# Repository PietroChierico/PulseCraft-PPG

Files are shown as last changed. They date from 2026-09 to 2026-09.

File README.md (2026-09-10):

# PulseCraft PPG

An open set of photoplethysmography (PPG) projects that go from a raw optical sensor to a live,
AI-assisted physiological demo. Five small projects, released so anyone can pick them up and
adapt them.






Each project comes with Arduino and ESP32 acquisition firmware, a 3D-printable case for the
MAX3010x sensor, Python code for recording data and extracting features, a small machine-learning
model, and a live GUI demo. A built-in signal simulator lets you run any of the wireless projects
with no hardware at all.

It was built end to end for the Khalifa University CMHS Summer Internship Program 2026, in the
Biomedical Engineering and Biotechnology track, and is free to reuse and adapt.

## The five projects

| # | Project | Question | Signal | Hardware |
|---|---|---|---|---|
| [01](projects/01-physical-activity-recognition/) | Physical activity recognition | Can we tell resting from walking by the motion artifact in PPG? | IR | Wireless (ESP32) |
| [02](projects/02-caffeine-response/) | Caffeine response | When do caffeine-related changes show up in PPG features? | IR | Wired or wireless |
| [03](projects/03-relaxation-score-game/) | Relaxation score game | How much does a 60 s breathing exercise change pulse and HRV features? | IR | Wired or wireless |
| [04](projects/04-biofeedback-spo2-apnea/) | Voluntary-apnea biofeedback | How do the Red and IR amplitudes move during a short, safe breath-hold? | Red + IR | Wired or wireless |
| [05](projects/05-mental-stress-detection/) | Mental stress detection | Can a model separate relaxed from stressed live? | IR | Wired or wireless |

Every project works the same way. You record a fixed protocol with a guided GUI, then you look at
the features and train a small model, then you run that model live on a fresh stream. Learn it
once and the other four have the same shape.

It was first run over about a week, with small groups sharing four sensor nodes.

## What you work through

- How optical PPG works, and why contact, pressure, skin tone and movement change the waveform.
- Basic filtering (detrending and band-pass) and what each step removes, with `visualize_filters.py`.
- Turning a windowed signal into features you can actually interpret.
- Training a small classifier and reading a confusion matrix instead of trusting one accuracy number.
- Running that model on a live signal and seeing where it breaks.
- Handling physiological data responsibly, and the limits of a non-medical device.

## Quick start without hardware

```bash
git clone https://github.com/PietroChierico/PulseCraft-PPG.git
cd PulseCraft-PPG
python -m venv .venv && source .venv/bin/activate   # Windows: .venv\Scripts\activate
pip install -r requirements.txt
```

Start the simulator in one terminal. It behaves exactly like the ESP32 firmware, streaming
`millis,red,ir` over TCP on `127.0.0.1:3333`.

```bash
python tools/ppg_simulator.py --scenario activity
```

Run a project against it in a second terminal. When it asks for a host and port, use `127.0.0.1`
and `3333`.

```bash
cd projects/01-physical-activity-recognition/wireless
python script1_dataset_collection_protocol.py
```

For real hardware, follow [docs/getting-started.md](docs/getting-started.md).

## Hardware

| Part | Example | Notes |
|---|---|---|
| PPG sensor | MAX30102 or MAX30105 breakout | I²C, Red and IR (plus green on the 30105) |
| Wired MCU | Arduino UNO or Nano | USB serial at 115200 baud |
| Wireless MCU | Adafruit Feather ESP32-C6 | WiFi TCP stream, runs on a battery |
| Case | `hardware/stl/` two-piece clip | Keeps the optical contact steady on a wrist or finger |

The full parts list, wiring tables, diagrams and firmware notes are in
[docs/hardware.md](docs/hardware.md).

## What is in the repo

```text
PulseCraft-PPG/
├── projects/     The five projects, each with collect, analyze/train and run-live steps
├── hardware/     Arduino and ESP32 firmware, and the 3D-printable case
├── tools/        ppg_simulator.py for the no-hardware mode, and check_setup.py
├── docs/         Getting started, hardware, signal processing, troubleshooting, FAQ
├── requirements.txt
├── CITATION.cff
├── LICENSE       MIT for code. MEDIA-LICENSE.md is CC BY 4.0 for the STL, photos and diagrams
└── SAFETY.md
```

## Citing

If you use PulseCraft PPG in a course, a workshop, a paper or another kit, please cite it with
[CITATION.cff](CITATION.cff). GitHub shows a "Cite this repository" button.

## License

Code is MIT ([LICENSE](LICENSE)). The STL files, photos and diagrams are CC BY 4.0
([MEDIA-LICENSE.md](MEDIA-LICENSE.md)). Keep attribution to Pietro Chierico when you reuse the
code or the media.

## Safety

For education and research prototyping. It is not a medical device, not a diagnostic tool, and
not for clinical decisions. Project 04 is a short, voluntary, supervised breath-hold and should be
stopped at any discomfort. See [SAFETY.md](SAFETY.md).

## Author

Pietro Chierico, PhD candidate in Biomedical Engineering. Built end to end during a visiting PhD
period at Khalifa University.

Visiting supervisor at Khalifa University, Prof. Mohamed Elgendi. Home PhD supervisor at
Universitat Politècnica de València, Prof. José Javier Rieta. Built for the CMHS Summer Internship
Program 2026, in the Biomedical Engineering and Biotechnology track.

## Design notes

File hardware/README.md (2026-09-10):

# Hardware

Acquisition firmware and the 3D-printable sensor case. The full guide, with the bill of
materials, wiring diagrams, network modes and sample-rate notes, is in
[../docs/hardware.md](../docs/hardware.md).

```text
hardware/
├── wired-arduino/     Arduino UNO and MAX3010x, USB serial at 115200
│   └── project-0X-*/  one streamer sketch per project
├── wireless-esp32/    Adafruit Feather ESP32-C6 and MAX3010x, WiFi TCP port 3333
│   └── project-0X-*/  one streamer sketch per project
└── stl/               two-piece MAX3010x clip enclosure, CC BY 4.0
```

## Which sketch

| Project | Wired | Wireless | Stream |
|---|---|---|---|
| 01, 02, 03, 05 | `wired-arduino/project-0X-ir-streamer/` | `wireless-esp32/project-0X-wifi-ir-streamer/` | IR, `time_us,ir` or `millis,red,ir` |
| 04 | `wired-arduino/project-04-red-ir-streamer/` | `wireless-esp32/project-04-wifi-red-ir-streamer/` | Red and IR |

The MCU only streams samples. All protocol and analysis logic is in the Python projects.

## Arduino library

SparkFun MAX3010x Pulse and Proximity Sensor Library (`MAX30105.h`), from the Arduino Library
Manager. ESP32 sketches also need the esp32 boards package.

## No hardware

`../tools/ppg_simulator.py` replaces the wireless firmware with a synthetic stream on
`127.0.0.1:3333`. Every wireless project runs against it.

## Sensor placement

Keep the contact gentle and steady. Hard pressure collapses perfusion and flattens the waveform.
A fingertip pad gives the strongest signal, a wrist is more realistic but noisier. Use the
printed case and a strap for motion-sensitive work.

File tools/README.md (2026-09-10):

# Tools

Small helpers that make the kit usable before you have hardware, and without it.

## `ppg_simulator.py`

Starts a TCP server that imitates the ESP32 wireless firmware. It accepts one client and then
streams `millis,red,ir` lines at a fixed rate.

```bash
python tools/ppg_simulator.py --scenario activity        # default port 3333
```

| `--scenario` | What it does |
|---|---|
| `plain` | clean resting PPG |
| `activity` | resting pulse with periodic walking bursts, for Project 01 |
| `caffeine` | heart rate drifts up over about 4 minutes, for Project 02 |
| `relaxation` | heart rate down, variability up after about 60 seconds, for Project 03 |
| `apnea` | baseline, then a Red and IR ratio shift during a roughly 30 second hold, then recovery, for Project 04 |
| `stress` | elevated heart rate, low variability, slight tremor, for Project 05 |

Other flags are `--host 0.0.0.0` to expose it on the LAN, `--port`, and `--rate` which defaults
to 100.

Point the project's script or GUI at host `127.0.0.1` and port `3333`. The whole loop, collect
then train then run live, works on simulated data, which is handy for getting familiar with a
project or for testing changes in CI.

## `check_setup.py`

```bash
python tools/check_setup.py                           # are all Python packages importable
python tools/check_setup.py --stream 127.0.0.1:3333   # measure the live sample rate
```

The `--stream` probe reads about 3 seconds and prints the measured rate and value range. If it
shows well under 100 Hz you have a rate mismatch to fix before recording. See
[../docs/hardware.md](../docs/hardware.md#sample-rate).

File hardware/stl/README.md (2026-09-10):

# 3D-printable MAX3010x enclosure

Two files.

- `max30102_base.stl`
- `max30102_shell.stl`

The enclosure steadies the optical contact during wrist or arm PPG recording. Print orientation,
strap fit and sensor tolerances may need small adjustments depending on your printer and your
specific MAX3010x breakout.

These models are licensed CC BY 4.0. Keep attribution to Pietro Chierico.

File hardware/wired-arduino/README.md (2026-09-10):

# Wired Arduino setup

These sketches stream PPG samples from a MAX30102 or MAX30105 to Python over USB serial at
115200 baud.

## Wiring

| MAX3010x | Arduino UNO |
|---|---|
| GND | GND |
| VIN | 3.3V |
| SDA | SDA |
| SCL | SCL |
| INT | not connected |

## Sketches

- `project-01-ir-streamer/arduino_ir_streamer.ino`
- `project-02-ir-streamer/arduino_ir_streamer.ino`
- `project-03-ir-streamer/arduino_ir_streamer.ino`
- `project-04-red-ir-streamer/arduino_red_ir_streamer.ino`
- `project-05-ir-streamer/arduino_ir_streamer.ino`

Close the Arduino IDE Serial Monitor before you connect from Python.

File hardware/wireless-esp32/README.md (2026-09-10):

# Wireless ESP32 setup

These sketches turn the ESP32 into a WiFi TCP PPG streamer.

## Wiring for the Adafruit Feather ESP32-C6

| MAX3010x | ESP32-C6 Feather |
|---|---|
| GND | GND |
| VIN | 3.3V |
| SDA | SDA / IO19 |
| SCL | SCL / IO18 |
| INT | not connected |

## Connection modes

By default the sketch first tries the router WiFi credentials. If those are left as
placeholders it starts an Access Point instead. Connect your computer to that Access Point and
use host `192.168.4.1` and port `3333`.

## Sketches

- `project-01-wifi-ir-streamer/esp32_wireless.ino`
- `project-02-wifi-ir-streamer/esp32_wireless.ino`
- `project-03-wifi-ir-streamer/esp32_wireless.ino`
- `project-04-wifi-red-ir-streamer/esp32_wireless_red_ir.ino`
- `project-05-wifi-ir-streamer/esp32_wireless.ino`

The sketches stream positive raw sensor counts. Project 04 is the only one that needs a paired
Red and IR stream for its Python workflow. The other wireless sketches also send Red and IR, but
the project code uses IR only.

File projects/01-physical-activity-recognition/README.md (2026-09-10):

# Project 01. Physical activity recognition

Can we tell resting from walking using only the motion artifact in a wrist or arm IR PPG signal?

| Item | Value |
|---|---|
| Signal | IR PPG |
| Hardware | Wireless ESP32 is the first choice. A wired Arduino sketch is included as a reference. |
| Feature window | 10 seconds |
| Roughly how long | about 45 minutes once the hardware or simulator is set up |
| No-hardware mode | `python tools/ppg_simulator.py --scenario activity` |

## How it goes

1. Collect with `script1_dataset_collection_protocol.py`. Follow the guided protocol, which is
   20 seconds to stabilise, 60 seconds resting, a 10 second pause, then 60 seconds walking. Each
   10 second window is saved as a labeled feature row. Repeat for several people.
2. Analyze and train with `script2_analysis_training_export.py`. Compare the feature
   distributions for resting against walking, pick a few features, train and test a small
   classifier, and export it.
3. Run live with `script3_live_classification.py`. Stream live, watch the model label resting or
   walking in real time, and try to fool it.

`wireless/Main_page.py` opens a one-page launcher with buttons for the three scripts.

## What you get out of it

Motion artifact is not just noise, it carries information. You see which features respond to
movement, such as derivative spread, high-frequency energy and the noise ratio, and which do not.
And you see why a model that scores perfectly in one room can still be learning the wrong thing.

## Run

```bash
pip install -r ../../../requirements.txt

# no hardware, in two terminals
python ../../../tools/ppg_simulator.py --scenario activity
cd wireless && python script1_dataset_collection_protocol.py    # host 127.0.0.1, port 3333

# real hardware
# flash hardware/wireless-esp32/project-01-wifi-ir-streamer, then use the ESP32 IP
```

## What to expect

With three or more clean sessions from two or more people, a simple classifier gets clearly above
chance. Walking windows show higher derivative standard deviation, higher noise-band energy and a
higher noise ratio. Accuracy across people is lower than within one person, which is a good thing
to discuss.

## Ideas to take it further

Add a third class such as stairs or arm swing. Swap the model for a small random forest and
compare. Split train and test strictly by person and report how much accuracy drops.

## Safety

An educational biomedical-signal demo. Not a medical device, and not for diagnosis or
safety-critical use.

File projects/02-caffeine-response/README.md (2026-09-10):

# Project 02. Caffeine response

How long after a coffee do caffeine-related changes show up in PPG features, and how much does
that differ from one person to another?

| Item | Value |
|---|---|
| Signal | IR PPG |
| Hardware | Wired Arduino or wireless ESP32 |
| Feature window | 10 seconds |
| Roughly how long | one session of about 40 minutes, then about 30 minutes of analysis. The recording spans roughly half an hour of real time. |
| No-hardware mode | `python tools/ppg_simulator.py --scenario caffeine` |

## How it goes

1. Collect with `script1_caffeine_dataset_collection_protocol.py`. Record a baseline, then
   sessions at +5, +10, +15, +20 and +25 minutes after the coffee. Each session is 15 seconds to
   stabilise and 60 seconds of recording, saved as 10 second feature windows tagged with the
   subject and the time point.
2. Analyze with `script2_caffeine_analysis_export.py`. Plot each feature as a change from that
   subject's baseline over time, and export summary CSVs and figures.
3. Interpret with `script3_caffeine_interpretation_assistant.py`. A GUI that helps you see when
   the response appears, which feature moves most, and how consistent it is across people.

## What you get out of it

You work against a personal baseline rather than absolute values. You have to think about
confounds like time of day, posture, temperature and whether the person has eaten, and how to
keep them under control. And you see that a well-known physiological effect can still be small,
noisy and very person-dependent.

## Run

```bash
pip install -r ../../../requirements.txt

python ../../../tools/ppg_simulator.py --scenario caffeine     # no hardware
cd wired && python app.py                                      # or  cd wireless && python app.py
```

## What to expect

Group-level trends, for example a modest shift in heart rate or pulse amplitude, usually appear
by +10 to +20 minutes. Individual curves vary a lot, and some people show almost nothing. That
variability is the point.

## Ideas to take it further

Run a blind decaf against caffeinated control. Fit the time to onset per person and compare it
with the caffeine pharmacokinetics literature.

## Safety

An educational demo. Not a medical device. Respect each participant's caffeine tolerance and
choices, and offer a decaf or no-coffee alternative.

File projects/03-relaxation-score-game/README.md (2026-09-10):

# Project 03. Relaxation score game

How much does one 60 second guided breathing exercise change pulse and heart-rate variability
features, and can we turn that into a live relaxation score?

| Item | Value |
|---|---|
| Signal | IR PPG |
| Hardware | Wired Arduino or wireless ESP32 |
| Feature window | 10 seconds |
| Roughly how long | about 30 minutes per participant |
| No-hardware mode | `python tools/ppg_simulator.py --scenario relaxation` |

## How it goes

1. Collect with `script1_relaxation_dataset_collection.py`. The phases are 20 seconds to
   stabilise, 60 seconds pre-relaxation which is saved, 60 seconds of guided deep breathing, and
   60 seconds post-relaxation which is saved.
2. Analyze and train with `script2_relaxation_analysis_training_export.py`. Quantify the shift
   from pre to post, and fit a model or a scoring function.
3. Play with `script3_relaxation_live_score_game.py`. A live score that rewards a calmer, slower,
   more variable pulse. Participants try breathing techniques to raise it.

## What you get out of it

Slow breathing, around 6 breaths per minute, increases HRV and respiratory sinus arrhythmia, and
you can see it in the waveform. You also see the difference between measuring a change of state
and classifying a person, and you have to design a score that motivates without being gamed by
simply holding still.

## Run

```bash
pip install -r ../../../requirements.txt

python ../../../tools/ppg_simulator.py --scenario relaxation
cd wired && python app_demo3_relaxation.py                     # or  cd wireless && python app_demo3_relaxation.py
```

## What to expect

Most participants show a lower pulse rate and higher beat-to-beat variability after the exercise.
The effect is usually clearer than the caffeine one, and it returns toward baseline within a few
minutes.

## Ideas to take it further

Compare box breathing, 4-7-8 breathing and paced 6 per minute breathing. Add a biofeedback bar
that animates with the breathing cycle.

## Safety

An educational demo. Not a medical device. If a participant feels light-headed during deep
breathing, stop and go back to normal breathing.

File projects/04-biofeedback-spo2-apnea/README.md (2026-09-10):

# Project 04. Voluntary-apnea biofeedback and SpO2 proxy

How do the Red and IR PPG amplitudes, and their ratio, move during a short, safe, voluntary
breath-hold, and what does that tell us about how a pulse oximeter works?

> Safety first. This is a short, voluntary, supervised activity. The participant controls the
> breath-hold and stops at the first sign of discomfort. Never push a breath-hold. The SpO2
> number is an uncalibrated educational proxy, not a measurement.

| Item | Value |
|---|---|
| Signal | Red and IR PPG, both channels are required |
| Hardware | Wired Arduino or wireless ESP32, dual-channel sketch |
| Window | 5 second rolling Red and IR ratio windows inside a full-trial CSV |
| Roughly how long | about 20 minutes per participant |
| No-hardware mode | `python tools/ppg_simulator.py --scenario apnea` |

## How it goes

1. Collect with `script1_spo2_apnea_collection.py`. The phases are 30 seconds of baseline, a
   voluntary apnea that the participant starts, then 60 seconds of recovery. Red and IR are
   recorded together.
2. Analyze with `script2_spo2_apnea_analysis.py`. Compute AC over DC for each channel and the
   ratio of ratios, then plot how it drifts during the hold and recovers afterward.
3. Challenge with `script3_spo2_apnea_interactive_challenge.py`. A live biofeedback view of the
   ratio and a proxy trend during a supervised hold.

## What you get out of it

You see why oximetry needs two wavelengths and uses `(AC/DC)_red / (AC/DC)_ir`, what a real
device calibrates with empirical curves and why this proxy is not that, and the physiological
lag, since the ratio keeps drifting for several seconds after breathing resumes.

## Run

```bash
pip install -r ../../../requirements.txt

python ../../../tools/ppg_simulator.py --scenario apnea
cd wired && python app_demo4_spo2_apnea.py                     # or  cd wireless && python app_demo4_spo2_apnea.py
```

Flash the red and ir sketch under `hardware/*/project-04-*red-ir*`.

## What to expect

During a 20 to 30 second hold the ratio of ratios shifts slightly and the proxy trends downward,
then overshoots and recovers over 30 to 60 seconds. The magnitudes vary and are not clinically
meaningful.

## Ideas to take it further

Compare finger against wrist placement. Add a simple two-point linear calibration against a real
fingertip oximeter, clearly labeled as a classroom exercise.

## Safety

See the box above and [../../SAFETY.md](../../SAFETY.md). Stop at once on dizziness, pain,
anxiety or shortness of breath. Not for anyone with a relevant cardiovascular or respiratory
condition.

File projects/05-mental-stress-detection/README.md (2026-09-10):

# Project 05. Mental stress detection

Can a small model separate relaxed from stressed, live, using PPG-derived waveform, pulse and HRV
features?

| Item | Value |
|---|---|
| Signal | IR PPG |
| Hardware | Wired Arduino or wireless ESP32 |
| Feature window | 10 seconds |
| Roughly how long | about 35 minutes to collect, then about 25 minutes of analysis |
| No-hardware mode | `python tools/ppg_simulator.py --scenario stress` |

## How it goes

1. Collect with `script1_stress_dataset_collection.py`. A multi-phase protocol that alternates
   calm baselines with cognitive stressors such as mental arithmetic, a timed reaction task and
   cognitive interference. Each 10 second window is labeled `Relaxed` or `Stressed`.
2. Analyze and train with `script2_stress_analysis_training_export.py`. See which features
   separate the classes, train and test, then export the model.
3. Challenge with `script3_stress_live_detection_challenge.py`. A live `Relaxed` against
   `Stressed` readout. Participants try to stay relaxed under a stressor.

## What you get out of it

Acute stress activates the sympathetic nervous system, which raises heart rate, lowers HRV and
subtly changes the waveform. Stress labels are noisy, since a stress task is not stressful for
everyone every time. You also deal with feature stability, class balance and why per-session
normalization matters.

## Run

```bash
pip install -r ../../../requirements.txt

python ../../../tools/ppg_simulator.py --scenario stress
cd wired && python app_demo5_stress.py                         # or  cd wireless && python app_demo5_stress.py
```

The wired serial format is shown in `wired/arduino_serial_ppg_format_example.ino`.

## What to expect

Accuracy within one person is usually good, and the model leans on HRV-proxy and pulse-rate
features. Generalization across people is weak with a small dataset, which is expected and worth
writing up.

## Ideas to take it further

Add a neutral third class and watch accuracy fall. Test the model on a fresh session recorded a
day later. Add a self-reported stress slider from 1 to 10 and correlate it with the model score.

## Safety

An educational demo. Not a medical device and not a psychological assessment. The stressor tasks
are mild and voluntary, and participants can stop at any time.

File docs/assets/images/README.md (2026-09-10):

# Image slots

Add your public setup photos here after checking them for privacy.

Some names that fit the docs.

- `hardware/wired-arduino-overview.jpg`
- `hardware/wireless-esp32-overview.jpg`
- `hardware/max30102-wiring-closeup.jpg`
- `stl/max30102-case-assembled.jpg`
- `project-04/red-ir-sensor-contact.jpg`

Avoid photos with faces, private notes, ID cards, or visible personal data unless you have
explicit permission.

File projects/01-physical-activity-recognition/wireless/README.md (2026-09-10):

# Project 01. Physical activity recognition, wireless workflow

This is the ESP32 WiFi version. Flash the matching sketch from `hardware/wireless-esp32/`. Use host `192.168.4.1` and port `3333` in the board's Access Point mode, or the IP from the Serial Monitor in router mode. With no hardware, run `tools/ppg_simulator.py` and use host `127.0.0.1`.

## Run

```bash
pip install -r ../../../requirements.txt
python ../../../tools/ppg_simulator.py --scenario activity   # no hardware, in a separate terminal
python Main_page.py   # a launcher page with buttons for the scripts below
# or run the steps in order
python script1_dataset_collection_protocol.py
python script2_analysis_training_export.py
python script3_live_classification.py
```

## Files

- `Main_page.py` is a small launcher page with buttons for the three scripts.
- `script1_dataset_collection_protocol.py` is step 1, collect a labeled dataset with a guided protocol.
- `script2_analysis_training_export.py` is step 2, look at the features, train and test a small model, then export it.
- `script3_live_classification.py` is step 3, stream live and classify or score in real time.
- `demo_1.py` is a helper.
- `ppg_feature_utils.py` is shared feature extraction.

## Notes

Keep the sample rate identical across collect, train and live. See `../../../docs/hardware.md`.

Do not commit recorded CSVs or trained models. `.gitignore` already blocks them.

Firmware for this version is under `hardware/wireless-esp32/project-01-*`.

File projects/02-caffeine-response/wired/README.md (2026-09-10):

# Project 02. Caffeine response, wired workflow

This is the Arduino serial version. Flash the matching sketch from `hardware/wired-arduino/`, then close the Arduino Serial Monitor before you connect from Python. Set the COM or tty port in the GUI (in Arduino IDE, under Tools then Port).

## Run

```bash
pip install -r ../../../requirements.txt
python app.py   # a launcher page with buttons for the scripts below
# or run the steps in order
python script1_caffeine_dataset_collection_protocol.py
python script2_caffeine_analysis_export.py
python script3_caffeine_interpretation_assistant.py
```

## Files

- `app.py` is a small launcher page with buttons for the three scripts.
- `script1_caffeine_dataset_collection_protocol.py` is step 1, collect a labeled dataset with a guided protocol.
- `script2_caffeine_analysis_export.py` is step 2, look at the features, train and test a small model, then export it.
- `script3_caffeine_interpretation_assistant.py` is step 3, stream live and classify or score in real time.
- `visualize_filters.py` is a live viewer for raw against filtered signal.

## Notes

Keep the sample rate identical across collect, train and live. See `../../../docs/hardware.md`.

Do not commit recorded CSVs or trained models. `.gitignore` already blocks them.

Firmware for this version is under `hardware/wired-arduino/project-02-*`.

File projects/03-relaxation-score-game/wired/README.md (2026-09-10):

# Project 03. Relaxation score game, wired workflow

This is the Arduino serial version. Flash the matching sketch from `hardware/wired-arduino/`, then close the Arduino Serial Monitor before you connect from Python. Set the COM or tty port in the GUI (in Arduino IDE, under Tools then Port).

## Run

```bash
pip install -r ../../../requirements.txt
python app_demo3_relaxation.py   # a launcher page with buttons for the scripts below
# or run the steps in order
python script1_relaxation_dataset_collection.py
python script2_relaxation_analysis_training_export.py
python script3_relaxation_live_score_game.py
```

## Files

- `app_demo3_relaxation.py` is a small launcher page with buttons for the three scripts.
- `script1_relaxation_dataset_collection.py` is step 1, collect a labeled dataset with a guided protocol.
- `script2_relaxation_analysis_training_export.py` is step 2, look at the features, train and test a small model, then export it.
- `script3_relaxation_live_score_game.py` is step 3, stream live and classify or score in real time.
- `visualize_filters.py` is a live viewer for raw against filtered signal.

## Notes

Keep the sample rate identical across collect, train and live. See `../../../docs/hardware.md`.

Do not commit recorded CSVs or trained models. `.gitignore` already blocks them.

Firmware for this version is under `hardware/wired-arduino/project-03-*`.

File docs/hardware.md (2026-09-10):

# Hardware

## Bill of materials

Per sensor node. Prices are rough 2026 street prices, for planning only.

| Part | Qty | ~USD | Notes |
|---|----:|-----:|---|
| MAX30102 or MAX30105 breakout | 1 | 5 to 12 | The 30105 adds a green LED. Either works. Prefer a board with a 3.3 V regulator and level shifting. |
| Arduino UNO or Nano (wired) | 1 | 8 to 25 | Any AVR board with I²C. |
| Adafruit Feather ESP32-C6 (wireless) | 1 | 15 to 20 | Other ESP32 boards work. Update the I²C pins in the sketch. |
| LiPo battery 400 to 1000 mAh (wireless) | 1 | 6 to 10 | JST-PH, for recording without a cable. |
| Dupont jumper wires | 4 | 1 | GND, 3V3, SDA, SCL. |
| USB cable | 1 | 2 | Data-capable, not charge-only. |
| 3D-printed case (`hardware/stl/`) | 1 | about 0.2 filament | Two-piece clip that steadies the optical contact. |
| Hook-and-loop strap | 1 | 1 | Holds the case on a wrist or finger. |

Twelve people in groups of three need four nodes. Budget one spare sensor.

## Wiring

The same four wires for every board. The MAX3010x runs at 3.3 V logic.

```text
 MAX3010x            Arduino UNO/Nano        Feather ESP32-C6
 --------            ---------------         ----------------
   GND  ------------------ GND ------------------ GND
   VIN  ------------------ 3.3V ----------------- 3.3V
   SDA  ------------------ A4 / SDA ------------- SDA (IO19)
   SCL  ------------------ A5 / SCL ------------- SCL (IO18)
   INT  ------  not connected  ------
```

```mermaid
flowchart LR
  S["MAX3010x sensor"] -- "I2C" --> M["MCU (Arduino UNO or ESP32-C6)"]
  M -- "USB serial 115200" --> PC1["PC, wired projects"]
  M -- "WiFi TCP port 3333, millis,red,ir" --> PC2["PC, wireless projects"]
  SIM["tools/ppg_simulator.py"] -. "no hardware" .-> PC2
```

## Firmware

The sketches live in `hardware/`. Each one is a self-contained streamer with no project logic on
the MCU.

| Project | Wired sketch | Wired stream | Wireless sketch | Wireless stream |
|---|---|---|---|---|
| 01, 02, 03, 05 | `wired-arduino/project-0X-ir-streamer/` | `time_us,ir` | `wireless-esp32/project-0X-wifi-ir-streamer/` | `millis,red,ir` |
| 04 | `wired-arduino/project-04-red-ir-streamer/` | `time_us,red,ir` | `wireless-esp32/project-04-wifi-red-ir-streamer/` | `red,infrared` |

The Python parsers take the last numeric value or values on each line, so timestamped and bare
formats both work. Projects 01 to 03 and 05 use IR only. Project 04 needs paired Red and IR.

### Required Arduino library

SparkFun MAX3010x Pulse and Proximity Sensor Library (`MAX30105.h`), installed from the Arduino
Library Manager. For ESP32 you also need the esp32 boards package.

### Wireless network modes

In Access Point mode, which is the default, leave `WIFI_SSID` and `WIFI_PASSWORD` on their
placeholders. The board creates `PPG_STREAM_groupN` with password `12345678`. Connect the PC's
WiFi to it and use host `192.168.4.1` and port `3333`. This is best for classrooms with
locked-down WiFi.

In router mode, set your WiFi credentials in the sketch, read the assigned IP from the Serial
Monitor, and use that IP with port `3333`.

## Sample rate

The sensor's effective output rate is `SAMPLE_RATE / SAMPLE_AVERAGE`.

| Sketch | `SAMPLE_RATE` | `SAMPLE_AVERAGE` | Effective rate | Matches the Python default of 100 Hz |
|---|---:|---:|---:|:--:|
| Wired Arduino (shipped) | 100 | 1 | 100 Hz | yes |
| Wireless ESP32 (shipped) | 100 | 1 | 100 Hz | yes |

Older copies of the ESP32 sketch shipped with `SAMPLE_AVERAGE = 4`, an effective 25 Hz, which did
not match the Python default. If `tools/check_setup.py --stream` shows about 25 Hz, set
`SAMPLE_AVERAGE = 1` in the sketch, or set `sampling_rate_hz = 25.0` in the project config.

If you deliberately change the rate or averaging, keep the value identical across collection,
training and live inference, and record the dataset again.

## Sensor placement

Keep the contact gentle and steady. Hard pressure collapses perfusion and flattens the waveform.
A fingertip pad gives the strongest signal. A wrist is more realistic but noisier. Shield the
sensor from strong direct light, and keep the cable still for the motion-sensitive Project 01.
Give the signal about 15 to 20 seconds to settle before recording. Every protocol already builds
that in.

## Photos

Add setup photos to `docs/assets/images/` under `hardware/`, `stl/` and `project-04/`. Avoid
faces, ID badges, screens showing participant data, and handwritten notes.

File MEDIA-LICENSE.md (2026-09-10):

# Media license

Code in this repository is under the MIT License in `LICENSE`.

The non-code assets are under the Creative Commons Attribution 4.0 International License
(CC BY 4.0). This covers the STL and 3D-printable files, setup photos, wiring diagrams, project
images, and any other visual or media assets added under `docs/assets/images/`.

Use this attribution line when you reuse or adapt them.

```text
PulseCraft PPG media assets by Pietro Chierico, licensed under CC BY 4.0.
```

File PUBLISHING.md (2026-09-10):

# Publishing and discoverability

Notes for publishing this repository, or a fork of it, and for making it easy to find.

## Before the first push

Check that nothing private is included.

- No CSVs, models, or `data/` and `results/` folders. `.gitignore` should already prevent this.
- Setup photos under `docs/assets/images/` have no faces, ID badges, screens showing participant
  data, or handwritten notes.
- No names beyond the author and the two named supervisors.

## Create the repo and push

```bash
git init
git add .
git commit -m "PulseCraft PPG 1.0.0"
git branch -M main
git remote add origin https://github.com/your-handle/PulseCraft-PPG.git
git push -u origin main
git tag v1.0.0 && git push --tags
```

## Repo settings that make it findable

Open the repo's About panel (the gear icon on the main page) and set the following.

Description.

```
Open photoplethysmography (PPG) projects. Arduino and ESP32 acquisition, a MAX30102 sensor case, Python feature extraction, small ML models, live demos, and a no-hardware simulator. Five small projects.
```

Website, `https://your-handle.github.io/PulseCraft-PPG/`.

Topics, added one at a time.

```
photoplethysmography  ppg  biomedical-signal-processing  wearable-sensing  digital-health
heart-rate-variability  pulse-oximetry  arduino  esp32  max30102  max30105  machine-learning
biomedical-engineering  stem-education  teaching-materials  open-educational-resources
signal-processing  python
```

In the repo settings, enable Issues and Discussions. Under Pages, set the source to a branch,
pick `main` and the `/docs` folder. Add a social preview image under Social preview, a photo of
the setup or a diagram works well.

For the first GitHub Release, tag `v1.0.0` and paste the 1.0.0 section of `CHANGELOG.md`.

## Optional, a citable DOI

Sign in to Zenodo with GitHub, turn on the switch for this repository in the Zenodo GitHub
settings, then publish a GitHub Release. Zenodo mints a DOI for it. Add the DOI badge to
`README.md` and a `doi:` field to `CITATION.cff`.

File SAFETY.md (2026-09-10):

# Safety and scope

## What this is

An educational and research-prototyping kit. It is not a medical device, not a diagnostic tool,
and not intended for clinical monitoring or clinical decisions.

PPG signals and every score derived from them depend heavily on sensor placement, motion,
contact pressure, ambient light, skin tone, individual physiology and calibration. Treat all
outputs as teaching artifacts.

## General rules

- Use it only for education and research prototyping.
- Do not use any output for medical diagnosis or clinical decisions.
- Keep sensor contact gentle. Too much pressure hurts and degrades the signal.
- Do not collect or publish participant data without the right consent and approvals. See
  [DATA_POLICY.md](DATA_POLICY.md).

## Extra rules for Project 04, voluntary apnea

- It is a short, voluntary, supervised activity only.
- The participant starts and ends the breath-hold, and stops at the first sign of discomfort.
- Never encourage longer holds, competition, or repeated holds.
- Stop at once on dizziness, pain, discomfort, anxiety, tingling, or shortness of breath.
- Not for anyone who is pregnant, or who has a cardiovascular, respiratory or seizure condition,
  or who is uncomfortable with the activity for any reason. Offer them the simulator scenario
  instead.
- The displayed SpO2 value is an uncalibrated educational proxy, not a measurement. Do not use it
  to reassure or alarm anyone.

## If you adapt this for a course

Follow your institution's ethics or IRB process for any human-subject data you keep or analyse
beyond a live in-class demo.

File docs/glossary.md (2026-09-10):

# Glossary

**PPG (photoplethysmography).** Measuring blood-volume changes in tissue from how much light a
skin site absorbs or reflects over time. The pulsatile part tracks the heartbeat.

**IR and Red channels.** The two LEDs on a MAX3010x. IR alone is enough for pulse-shape work.
The Red and IR pair together is used for oxygenation proxies.

**AC and DC components.** DC is the slowly varying baseline from tissue and venous blood. AC is
the pulsatile component from arterial pulsation.

**Motion artifact.** Signal corruption from the sensor moving against the skin. It dominates
Project 01.

**Detrending, or high-pass filter.** Removing the slow baseline so the pulse is centred on zero.

**Band-pass filter.** Keeping only a frequency band, here about 0.5 to 3 Hz, the heart-rate range.

**Feature window.** A fixed-length slice of signal, 5 to 10 seconds, summarised into a row of
numbers.

**Feature.** One number describing a window, for example spectral centroid or derivative
standard deviation.

**HRV (heart-rate variability).** Beat-to-beat timing variation, a proxy for autonomic balance.

**Ratio of ratios.** `(AC_red/DC_red) / (AC_ir/DC_ir)`, the quantity a pulse oximeter calibrates
into SpO2. It is left uncalibrated here.

**SpO2.** Peripheral blood oxygen saturation. Project 04 outputs a proxy, not a measurement.

**Confusion matrix.** A table of predicted against true labels, the honest way to read classifier
performance.

**Leakage.** When information from the test set reaches training, for example the same recording
session on both sides, which inflates accuracy.

**Access Point (AP) mode.** The ESP32 makes its own WiFi network instead of joining a router.

**Sampling rate.** Samples per second. It must be identical across collection, training and live
inference.

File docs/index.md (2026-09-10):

# PulseCraft PPG

An open set of photoplethysmography (PPG) projects that go from a raw optical sensor to a live,
AI-assisted physiological demo.

Arduino and ESP32 acquisition firmware, a 3D-printable MAX3010x case, Python code for recording
data and extracting features, small machine-learning models, live GUI demos, and a signal
simulator so you can run everything before any hardware arrives.

Code is at <https://github.com/PietroChierico/PulseCraft-PPG>.

Start with [Getting started](getting-started.md). See also [Hardware](hardware.md),
[Signal processing](signal-processing.md),
[Signal-quality checklist](signal-quality-checklist.md),
[Troubleshooting](troubleshooting.md), [FAQ](faq.md) and [Glossary](glossary.md).

## Projects

| # | Project | Signal | Hardware |
|---|---|---|---|
| 01 | Physical activity recognition (resting vs walking) | IR | Wireless |
| 02 | Caffeine response over time | IR | Wired or wireless |
| 03 | Relaxation score game (breathing) | IR | Wired or wireless |
| 04 | Voluntary-apnea biofeedback with a SpO2 proxy | Red + IR | Wired or wireless |
| 05 | Mental stress detection (live classifier) | IR | Wired or wireless |

See [Project protocols](project-protocols.md) for the recording steps.

## Attribution

Designed and built by **Pietro Chierico** during a visiting PhD period at **Khalifa University**.
Visiting supervisor at Khalifa University, **Prof. Mohamed Elgendi**. Home PhD supervisor at
Universitat Politècnica de València, **Prof. José Javier Rieta**. Built for the **CMHS Summer
Internship Program 2026**, in the Biomedical Engineering and Biotechnology track.

For education and research only. Not a medical device.

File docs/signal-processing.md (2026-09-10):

# Signal processing, in brief

This is the conceptual map. The exact details are in each project's `ppg_*_features.py` or
`ppg_feature_utils.py`.

## Pipeline

Raw counts become a window of 5 to 10 seconds. The window is detrended and band-passed, then
turned into features. A small model maps the features to a label or a score.

## 1. Windowing

The stream is cut into fixed windows, 10 seconds for projects 01 to 03 and 05, and a 5 second
rolling window for the SpO2 proxy in 04. One window makes one feature row. The window is the
unit of both training and live prediction.

## 2. Filtering

A high-pass around 0.5 Hz removes the slow baseline wander from breathing and perfusion drift, so
the pulse sits on zero. A band-pass of roughly 0.5 to 3 or 4 Hz keeps the heart-rate band and
attenuates DC and high-frequency noise. Run `visualize_filters.py` in any project to see raw
against filtered, live, and get a feel for what each filter throws away.

The filtering is kept simple and causal-friendly so the same ideas carry over to an embedded or
wearable context.

## 3. Features

| Group | Examples | Reads as |
|---|---|---|
| Amplitude and spread | mean, std, 5 to 95 percent range, IQR, detrended std | perfusion strength, gross motion |
| Shape and derivative | mean absolute derivative, derivative std, zero-crossing rate | steepness and regularity of the pulse |
| Spectral | pulse-band energy, noise-band energy, noise ratio, spectral centroid | how clean the signal is and where its energy sits |
| Rate and variability (03, 05) | pulse rate, inter-beat interval, HRV proxies | autonomic state |
| Red and IR ratio (04 only) | ratio of ratios, AC over DC per channel | oxygenation proxy, not calibrated SpO2 |

The features are chosen to be interpretable. You should be able to say why a feature moved, not
just that the model score changed.

## 4. Model

A small scikit-learn classifier, either logistic regression or a small tree ensemble depending
on the project. It is kept small on purpose. It trains in seconds on a class-sized dataset, the
decision boundary can be inspected feature by feature in `script2_*`, and its size forces the
question of whether a result is real physiology or just the room.

Always read the confusion matrix, and test on a session the model never saw.

## 5. Honest limits

PPG features depend on placement, contact pressure, skin tone, ambient light, motion and
individual physiology. Cross-subject models are weak with small datasets. The SpO2 value in
Project 04 is an educational ratio proxy, not a validated measurement. Treat every output as a
teaching artifact.

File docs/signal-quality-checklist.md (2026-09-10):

# Signal-quality checklist

Run through this before trusting any recording.

- [ ] Sensor powered from 3.3 V, not 5 V.
- [ ] Serial Monitor closed for wired, or the right host and port for wireless.
- [ ] `python tools/check_setup.py --stream <host:port>` shows about 100 Hz, or your configured rate.
- [ ] Sensor resting on the skin with light, steady contact, not pressed.
- [ ] Consistent measurement site (fingertip pad, wrist, and so on), and note which one.
- [ ] Cable and board still and supported. This matters most for Project 01.
- [ ] Not under strong direct light.
- [ ] Full stabilisation phase waited out before recording.
- [ ] Band-pass output in `visualize_filters.py` looks like a clean, regular pulse.
- [ ] No flat-topping or clipping at the top or bottom of the raw trace.

A quick sanity check. Estimate the heart rate by eye from the band-pass trace and confirm it
matches the person. If the waveform is flat, clipped or irregular, fix the setup and record
again.

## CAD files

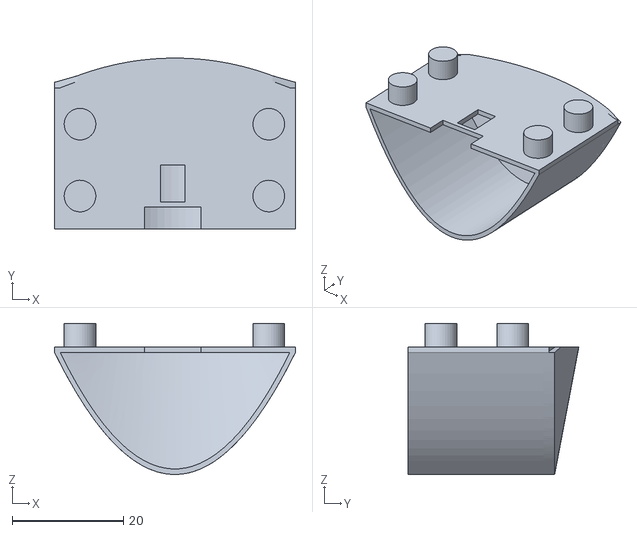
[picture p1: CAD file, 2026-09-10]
hardware/stl/max30102_shell.stl
43.4 x 30.8 x 27.2

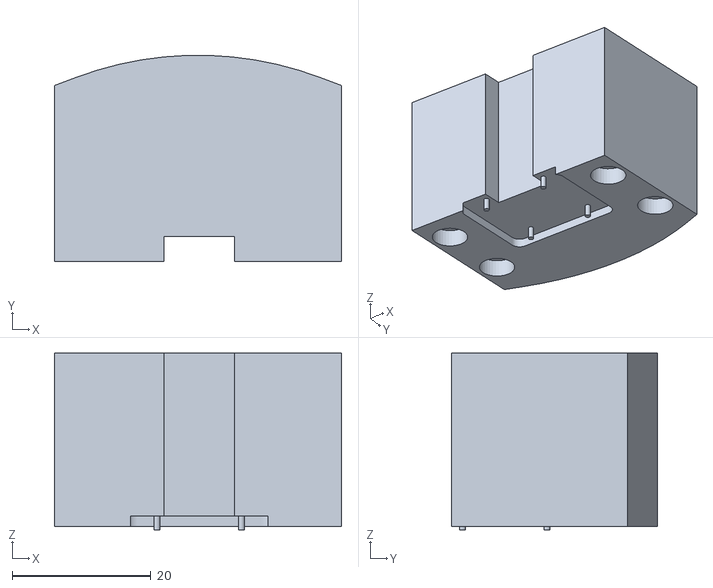
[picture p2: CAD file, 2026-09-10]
hardware/stl/max30102_base.stl
41.4 x 29.7 x 25.5

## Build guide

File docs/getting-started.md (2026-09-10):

# Getting started

There are two paths. Do A first, since it needs no hardware and takes about five minutes. Then
do B when you have a sensor.

## A. Run a project with the simulator

```bash
python -m venv .venv && source .venv/bin/activate     # Windows: .venv\Scripts\activate
pip install -r requirements.txt
python tools/check_setup.py                            # confirms the environment
```

Start the synthetic stream. It behaves like the ESP32 firmware, running a TCP server on port
3333 and sending `millis,red,ir` lines at 100 Hz.

```bash
python tools/ppg_simulator.py --scenario activity      # also caffeine, relaxation, apnea, stress
```

In a second terminal, run any wireless project. When a script asks for a host and a port, use
`127.0.0.1` and `3333`.

```bash
cd projects/01-physical-activity-recognition/wireless
python script1_dataset_collection_protocol.py
```

You can do the whole loop, collect then train then run live, entirely on simulated data. This is
the easiest way to get familiar with a project before the hardware is set up.

## B. Run a project with real hardware

### 1. Build the sensor node

Wire the MAX3010x to the board using the tables in [hardware.md](hardware.md), and print the case
in `hardware/stl/` if you want one.

### 2. Flash the firmware

Install the Arduino IDE and the SparkFun MAX3010x library (Library Manager, search "MAX3010x").

For the wired setup, open `hardware/wired-arduino/project-0X-*/*.ino`, select your board and
port, and upload. Close the Serial Monitor afterwards, because Python needs the port.

For the wireless setup, open `hardware/wireless-esp32/project-0X-*/*.ino`. Leave the WiFi fields
on their placeholders and the board makes its own network `PPG_STREAM_groupN` (password
`12345678`), or enter your router credentials instead. Upload, then open the Serial Monitor once
to read the IP.

### 3. Connect

For the wired setup, find the COM or tty port in Arduino IDE under Tools then Port. The Python
GUI has a port field.

For the wireless setup on the board's own network, connect your computer's WiFi to
`PPG_STREAM_groupN`, then use host `192.168.4.1` and port `3333`. In router mode, use the IP
printed in the Serial Monitor and port `3333`.

Check the stream first with `python tools/check_setup.py --stream 192.168.4.1:3333`. It reports
the measured sample rate and a short waveform preview.

### 4. Run the project

Open the project folder and follow its `README.md`. Each project has an `app.py` launcher, a
small local web page with buttons, and three numbered scripts you can also run directly.

```text
script1_*   collect a labeled dataset with a guided protocol
script2_*   analyze features, train and test a model, export it
script3_*   stream live and classify or score in real time
```

Before a real recording, run through the [signal-quality checklist](signal-quality-checklist.md).

## Sample rate must match everywhere

Collection, training and live inference all assume the same sample rate. The Python config
default is 100 Hz. If you change the firmware sample rate or averaging, update `sampling_rate_hz`
in the project config and record again. See [hardware.md](hardware.md#sample-rate).

## If something breaks

See [troubleshooting.md](troubleshooting.md). The usual causes are a Serial Monitor left open,
the wrong host or port, the sensor not touching skin properly, and a sample-rate mismatch.

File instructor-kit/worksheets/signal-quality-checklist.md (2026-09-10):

# Signal-quality checklist

Group: _______________  Node ID: ______  Date/time: ______________

Run through this before you trust any recording.

- [ ] Sensor powered from **3.3 V** (not 5 V).
- [ ] Serial Monitor closed (wired) / correct host + port (wireless).
- [ ] `python tools/check_setup.py --stream <host:port>` shows **~100 Hz** (or your configured rate).
- [ ] Sensor rests on the skin with **light, steady** contact — not pressed.
- [ ] Site chosen and recorded: ☐ fingertip pad ☐ wrist ☐ other: ______
- [ ] Cable/board is still and supported (critical for Project 01).
- [ ] Not under strong direct light.
- [ ] Waited the full stabilisation phase before recording.
- [ ] Band-pass output in `visualize_filters.py` looks like a clean, regular pulse.
- [ ] No flat-topping / clipping at the top or bottom of the raw trace.

**Attach:** one screenshot of raw vs band-pass, annotated with the heart rate you estimate by eye.

Estimated heart rate by eye: ______ bpm  ·  Looks clean? ☐ yes ☐ borderline ☐ re-record

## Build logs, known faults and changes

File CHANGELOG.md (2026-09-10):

# Changelog

The format loosely follows [Keep a Changelog](https://keepachangelog.com/). Versioning is
semantic.

## 1.0.0, 2026-09

First public release.

- Five projects (activity recognition, caffeine response, relaxation, an apnea and SpO2 proxy,
  stress detection). Each one follows the same collect, analyze and train, run live pattern, in
  wired and wireless variants.
- Arduino UNO and Adafruit Feather ESP32-C6 acquisition firmware. The ESP32 sketches stream a
  true 100 Hz (`SAMPLE_AVERAGE = 1`) to match the Python `sampling_rate_hz` default.
- Two-piece 3D-printable MAX3010x enclosure in `hardware/stl/`.
- `tools/ppg_simulator.py`, a synthetic Red and IR TCP stream so every wireless project runs
  with no hardware, with six scenario presets.
- `tools/check_setup.py`, an environment and live-stream sample-rate check.
- `docs/` covering getting started, hardware, signal processing, the signal-quality checklist,
  troubleshooting, an FAQ, a glossary and the project protocols.
- GitHub scaffolding, issue and PR templates, a Code of Conduct, `CITATION.cff`, and a CI syntax
  check.

### Notes

The firmware is checked statically only. It has not been re-tested on hardware for this release.

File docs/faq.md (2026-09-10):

# FAQ

**Do I need hardware to try this?**
No. `tools/ppg_simulator.py` produces synthetic Red and IR PPG on TCP `127.0.0.1:3333`, exactly
like the ESP32 firmware. Every wireless project runs against it end to end.

**Which sensor should I buy?**
A MAX30102 or a MAX30105. Either one works. The 30105 adds a green LED that is unused here. Pick
a breakout with an onboard 3.3 V regulator.

**Arduino or ESP32?**
Wired Arduino is the simplest and most stable option on a lab bench. Wireless ESP32 is better for
the motion projects and for a wearable feel. Projects 02 to 05 support both. Project 01 is
wireless first.

**How much time does it take?**
Each project is a short session once the hardware or the simulator is ready. The first run took
about a week with small groups, but the projects are independent, so do one or all five at
whatever pace suits you.

**Can I keep the recordings?**
Yes, locally. Do not commit them. `.gitignore` blocks CSVs, models and output folders by
default. See `DATA_POLICY.md`.

**Is the SpO2 number in Project 04 real?**
No. It is an uncalibrated ratio-of-ratios proxy for teaching. It is not a pulse oximeter.

**Can I use a different board, a Raspberry Pi, or phone-camera PPG?**
The Python side only needs a line-based stream of numbers. Any source that sends `ir` or
`millis,red,ir` lines over serial or TCP will work. Change the host and port, or the serial port
name, in the GUI.

**Why are the models so small?**
So they train in seconds on a laptop, stay interpretable, and make overfitting on a small
dataset obvious. Swapping in a bigger model is an easy next step.

**What can I change and redistribute?**
Everything. Code is MIT, media is CC BY 4.0. Keep attribution to Pietro Chierico and cite the
repo.

**How do I cite it?**
Use `CITATION.cff`. GitHub shows a "Cite this repository" button. Add a Zenodo DOI after your
first release if you want a permanent citation.

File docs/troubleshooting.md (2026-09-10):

# Troubleshooting

## Setup

| Symptom | Cause | Fix |
|---|---|-----|
| `check_setup.py` reports missing packages | venv not active, or dependencies not installed | Run `pip install -r requirements.txt` inside the activated venv |
| `MAX3010x not found` on the Serial Monitor | wiring or power | Check SDA to SDA, SCL to SCL, VIN to 3.3 V and not 5 V, and a solid GND. Try the other I²C connector on the breakout. |
| Arduino uploads but no data appears | Serial Monitor baud is not 115200 | Set it to 115200, or just close it and connect from Python |

## Connection

| Symptom | Cause | Fix |
|---|---|-----|
| Python cannot open the COM or tty port | Arduino Serial Monitor still open, or wrong port | Close the Monitor, then pick the port shown in Arduino IDE under Tools, Port |
| Wireless connection refused or times out | wrong host or port, or not on the board's network | In AP mode join `PPG_STREAM_groupN`, host `192.168.4.1`, port `3333`. In router mode use the IP from the Serial Monitor. |
| Wireless drops after a few seconds | weak WiFi, or the board browns out on battery | Move closer, use a charged battery or USB, and lower `LED_BRIGHTNESS` |
| `tools/check_setup.py --stream` shows about 25 Hz | ESP32 sketch has `SAMPLE_AVERAGE = 4` | Set it to `1`, or set `sampling_rate_hz = 25.0` in the project config |

## Signal quality

| Symptom | Cause | Fix |
|---|---|-----|
| Flat or tiny waveform | poor contact, or pressing too hard | Rest the sensor lightly. A fingertip pad gives the strongest signal. |
| Waveform clips at the top or bottom | `LED_BRIGHTNESS` or `ADC_RANGE` | Lower the brightness, or raise the ADC range in the sketch |
| Large low-frequency swings | breathing or hand movement | Wait out the 15 to 20 second stabilisation, keep the hand still, use the case and strap |
| Live classifier flips constantly | sample-rate mismatch, or too little training data | Record again at the real rate, collect more sessions, and check the confusion matrix in `script2_*` |

## Analysis and training

| Symptom | Cause | Fix |
|---|---|-----|
| `script2` finds no CSV | run from the wrong folder, or `script1` never saved | Run from the project's `wired/` or `wireless/` folder, and complete a full protocol in `script1` |
| Model accuracy near 100 percent | leakage, the same session in train and test, or a trivial feature | Split by session, and drop features like `raw_mean` that only encode LED brightness |
| GUI will not start on Linux | missing Qt platform libraries | `sudo apt install libxcb-cursor0 libxkbcommon-x11-0` |

Still stuck? Open an issue with the OS, the Python version, wired or wireless, the exact command,
and the full error text. The templates are in `.github/ISSUE_TEMPLATE/`.

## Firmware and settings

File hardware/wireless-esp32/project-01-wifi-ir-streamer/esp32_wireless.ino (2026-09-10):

// Copyright (c) 2026 Pietro Chierico
// SPDX-License-Identifier: MIT

/*
  ESP32-C6 Feather + MAX30102 / MAX30105 PPG WiFi Streamer

  Board:
    Adafruit Feather ESP32-C6

  Sensor:
    I2C PPG sensor, for example MAX30102 or MAX30105

  Wiring:
    Sensor GND  -> Feather GND
    Sensor VIN  -> Feather 3.3V
    Sensor SDA  -> Feather SDA / IO19
    Sensor SCL  -> Feather SCL / IO18
    Sensor INT  -> Not connected

  TCP stream format:
    millis,red,ir

  PC connects to:
    AP mode: 192.168.4.1 port 3333
    WiFi router mode: use the IP printed in Serial Monitor
*/

#include <WiFi.h>
#include <Wire.h>
#include "MAX30105.h"

// ESP32-C6 Feather I2C pins
#define I2C_SDA_PIN 19
#define I2C_SCL_PIN 18

// Leave these as they are to make the ESP32 create its own WiFi network.
// Or put your router WiFi name/password here.
const char* WIFI_SSID     = "YOUR_WIFI_NAME";
const char* WIFI_PASSWORD = "YOUR_WIFI_PASSWORD";

// Fallback Access Point settings
const char* AP_SSID     = "PPG_STREAM_group1";
const char* AP_PASSWORD = "12345678";   // Must be at least 8 characters

const uint16_t TCP_PORT = 3333;
const uint32_t WIFI_TIMEOUT_MS = 15000;

WiFiServer server(TCP_PORT);
WiFiClient client;
MAX30105 ppg;

// Sensor settings
// Increase LED_BRIGHTNESS if the signal is too weak.
// Decrease it if the sensor gets warm or battery life is poor.
const byte LED_BRIGHTNESS = 0x1F;  // 0x00 to 0xFF
const byte SAMPLE_AVERAGE = 1;   // 1 => true 100 Hz output, matches the Python sampling_rate_hz default. Was 4 (=> 25 Hz).
const byte LED_MODE = 2;           // 1 = Red only, 2 = Red + IR, 3 = Red + IR + Green
const int SAMPLE_RATE = 100;       // Hz
const int PULSE_WIDTH = 411;       // 69, 118, 215, 411
const int ADC_RANGE = 16384;       // 2048, 4096, 8192, 16384

bool usingAccessPoint = false;

// NEO: Set onboard NeoPixel color.
// Values are low brightness to avoid too much power use.
void setNeoColor(uint8_t red, uint8_t green, uint8_t blue) {
#if defined(PIN_NEOPIXEL)
  neopixelWrite(PIN_NEOPIXEL, red, green, blue);
#endif
}

// NEO: Initialize onboard NeoPixel pin.
void setupNeoPixel() {
#if defined(PIN_NEOPIXEL)
  pinMode(PIN_NEOPIXEL, OUTPUT);
  setNeoColor(32, 8, 0);   // Orange: boot
#endif
}

void startAccessPoint() {
  WiFi.mode(WIFI_AP);
  WiFi.softAP(AP_SSID, AP_PASSWORD);

  IPAddress ip = WiFi.softAPIP();
  usingAccessPoint = true;

  setNeoColor(32, 0, 32);  // Purple: fallback AP active

  Serial.println();
  Serial.println("Started ESP32 Access Point.");
  Serial.print("WiFi network: ");
  Serial.println(AP_SSID);
  Serial.print("Password: ");
  Serial.println(AP_PASSWORD);
  Serial.print("Connect your PC to this WiFi, then connect to IP: ");
  Serial.println(ip);
  Serial.print("TCP port: ");
  Serial.println(TCP_PORT);
}

void connectWiFi() {
  bool credentialsChanged =
    strcmp(WIFI_SSID, "YOUR_WIFI_NAME") != 0 &&
    strlen(WIFI_SSID) > 0;

  if (!credentialsChanged) {
    startAccessPoint();
    return;
  }

  WiFi.mode(WIFI_STA);
  WiFi.setSleep(false);

  setNeoColor(0, 0, 32);   // Blue: connecting to router WiFi

  WiFi.begin(WIFI_SSID, WIFI_PASSWORD);

  Serial.println();
  Serial.print("Connecting to WiFi: ");
  Serial.println(WIFI_SSID);

  uint32_t startAttempt = millis();

  while (WiFi.status() != WL_CONNECTED &&
         millis() - startAttempt < WIFI_TIMEOUT_MS) {
    delay(500);
    Serial.print(".");
  }

  Serial.println();

  if (WiFi.status() == WL_CONNECTED) {
    usingAccessPoint = false;

    setNeoColor(0, 32, 0);   // Green: connected to router WiFi

    Serial.println("Connected to router WiFi.");
    Serial.print("ESP32 IP address: ");
    Serial.println(WiFi.localIP());
    Serial.print("TCP port: ");
    Serial.println(TCP_PORT);
  } else {
    Serial.println("Could not connect to router WiFi. Starting fallback AP.");
    WiFi.disconnect(true);
    delay(500);
    startAccessPoint();
  }
}

void setupSensor() {
  Serial.println("Starting I2C...");

  setNeoColor(32, 8, 0);   // Orange: sensor starting

  // The ESP32-C6 Feather uses SDA IO19 and SCL IO18.
  Wire.begin(I2C_SDA_PIN, I2C_SCL_PIN);
  Wire.setClock(400000);

  Serial.println("Searching for MAX3010x sensor...");

  if (!ppg.begin(Wire, I2C_SPEED_FAST)) {
    setNeoColor(64, 0, 0);   // Red: sensor error

    Serial.println("ERROR: MAX3010x sensor not found.");
    Serial.println("Check GND, 3.3V, SDA, and SCL connections.");
    while (true) {
      delay(1000);
    }
  }

  ppg.setup(
    LED_BRIGHTNESS,
    SAMPLE_AVERAGE,
    LED_MODE,
    SAMPLE_RATE,
    PULSE_WIDTH,
    ADC_RANGE
  );

  ppg.clearFIFO();

  Serial.println("MAX3010x sensor found and configured.");
  Serial.println("Stream format: millis,red,ir");
}

void acceptClientIfNeeded() {
  if (client && client.connected()) {
    return;
  }

  WiFiClient newClient = server.available();

  if (newClient) {
    if (client) {
      client.stop();
    }

    client = newClient;
    client.setNoDelay(true);

    client.println("millis,red,ir");

    setNeoColor(0, 32, 32);   // Cyan: PC connected to TCP stream

    Serial.println();
    Serial.println("PC connected to PPG stream.");
  }
}
void streamSample(int32_t red, int32_t ir) {
  char line[64];

  int n = snprintf(
    line,
    sizeof(line),
    "%lu,%ld,%ld\n",
    (unsigned long)millis(),
    (long)red,
    (long)ir
  );

  Serial.write((const uint8_t*)line, n);

  if (client && client.connected()) {
    client.write((const uint8_t*)line, n);
  }
}

void setup() {
  Serial.begin(115200);
  delay(2000);

  Serial.println();
  Serial.println("ESP32-C6 Feather PPG WiFi Streamer");

#if defined(NEOPIXEL_I2C_POWER)
  // On the Feather this pin powers the STEMMA QT / I2C connector.
  pinMode(NEOPIXEL_I2C_POWER, OUTPUT);
  digitalWrite(NEOPIXEL_I2C_POWER, HIGH);
#endif

  setupNeoPixel();

  setupSensor();
  connectWiFi();

  server.begin();

  Serial.println();
  Serial.println("TCP server started.");
  Serial.println("Place your finger gently on the PPG sensor.");
}

void loop() {
  acceptClientIfNeeded();

  // Read all samples waiting in the MAX3010x FIFO.
  ppg.check();

while (ppg.available()) {
  int32_t red = (int32_t)ppg.getFIFORed();
  int32_t ir  = (int32_t)ppg.getFIFOIR();

  streamSample(red, ir);

  ppg.nextSample();
}

  // Optional: allow the PC to disconnect by sending x.
  if (client && client.connected() && client.available()) {
    char c = client.read();
    if (c == 'x' || c == 'X') {
      client.stop();

      if (usingAccessPoint) {
        setNeoColor(32, 0, 32);  // Purple: AP still active
      } else {
        setNeoColor(0, 32, 0);   // Green: router WiFi still connected
      }

      Serial.println("PC disconnected.");
    }
  }
}

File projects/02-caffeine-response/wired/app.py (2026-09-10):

# Copyright (c) 2026 Pietro Chierico
# SPDX-License-Identifier: MIT

import os
import sys
import subprocess
import webbrowser
from pathlib import Path
from flask import Flask, render_template_string, jsonify

app = Flask(__name__)

BASE_DIR = Path(__file__).parent.resolve()

SCRIPT_MAIN = BASE_DIR / "visualize_filters.py"
SCRIPT_1 = BASE_DIR / "script1_caffeine_dataset_collection_protocol.py"
SCRIPT_2 = BASE_DIR / "script2_caffeine_analysis_export.py"
SCRIPT_3 = BASE_DIR / "script3_caffeine_interpretation_assistant.py"

HTML_PAGE = """
<!DOCTYPE html>
<html lang="en">
<head>
    <meta charset="UTF-8">
    <title>PulseCraft PPG</title>

    <style>
        :root {
            --bg: #f5f7fb;
            --text: #111114;
            --muted: #5f6368;
            --blue: #0071e3;
            --dark: #0b0f19;
            --card: rgba(255, 255, 255, 0.78);
            --glass: rgba(255, 255, 255, 0.58);
            --border: rgba(255, 255, 255, 0.45);
        }

        * { box-sizing: border-box; }

        body {
            margin: 0;
            font-family: -apple-system, BlinkMacSystemFont, "Segoe UI", sans-serif;
            background:
                radial-gradient(circle at top left, #d9e8ff 0%, transparent 32%),
                radial-gradient(circle at top right, #e8ddff 0%, transparent 30%),
                linear-gradient(180deg, #f8fbff 0%, #eef2f8 100%);
            color: var(--text);
        }

        header {
            min-height: 92vh;
            padding: 40px 10% 80px;
            position: relative;
            display: flex;
            flex-direction: column;
            justify-content: center;
            overflow: hidden;
        }

        header::after {
            content: "";
            position: absolute;
            width: 520px;
            height: 520px;
            right: -120px;
            top: 130px;
            background: radial-gradient(circle, rgba(0,113,227,0.22), transparent 68%);
            filter: blur(8px);
            z-index: 0;
        }

        .top-bar {
            position: absolute;
            top: 34px;
            left: 10%;
            right: 10%;
            display: flex;
            justify-content: space-between;
            align-items: center;
            z-index: 2;
        }

        .logo {
            height: 86px;
            border-radius: 18px;
            box-shadow: 0 18px 45px rgba(0,0,0,0.12);
        }

        .nav-pill {
            padding: 12px 20px;
            border-radius: 999px;
            background: var(--glass);
            backdrop-filter: blur(18px);
            font-weight: 700;
            color: #1d1d1f;
            border: 1px solid var(--border);
        }

        .hero { max-width: 950px; z-index: 2; }

        .tag {
            display: inline-block;
            background: rgba(0,113,227,0.10);
            color: var(--blue);
            padding: 9px 18px;
            border-radius: 999px;
            font-weight: 700;
            margin-bottom: 24px;
        }

        h1 {
            font-size: clamp(54px, 8vw, 112px);
            line-height: 0.95;
            margin: 0 0 28px;
            letter-spacing: -5px;
        }

        h2 {
            font-size: clamp(34px, 4vw, 56px);
            letter-spacing: -2px;
            margin: 0 0 18px;
        }

        h3 { font-size: 24px; margin-bottom: 10px; }

        p { font-size: 20px; line-height: 1.65; color: var(--muted); }
        .hero p { max-width: 760px; font-size: 24px; }
        section { padding: 70px 10%; }

        .card {
            background: var(--card);
            backdrop-filter: blur(24px);
            border: 1px solid var(--border);
            border-radius: 34px;
            padding: 46px;
            box-shadow: 0 28px 70px rgba(25, 35, 60, 0.12);
            margin-bottom: 46px;
        }

        .dark-card {
            background:
                radial-gradient(circle at top left, rgba(0,113,227,0.34), transparent 32%),
                linear-gradient(135deg, #0b0f19, #161b2d);
            color: white;
        }

        .dark-card p { color: #c9d2e3; }

        .grid {
            display: grid;
            grid-template-columns: repeat(auto-fit, minmax(230px, 1fr));
            gap: 18px;
            margin-top: 32px;
        }

        .mini-card {
            padding: 26px;
            border-radius: 26px;
            background: rgba(255,255,255,0.70);
            border: 1px solid rgba(255,255,255,0.55);
        }

        .dark-card .mini-card {
            background: rgba(255,255,255,0.08);
            border: 1px solid rgba(255,255,255,0.12);
        }

        .mini-card span {
            display: block;
            color: var(--blue);
            font-weight: 800;
            margin-bottom: 12px;
        }

        .dark-card .mini-card span { color: #7ab8ff; }

        button {
            border: none;
            border-radius: 999px;
            padding: 17px 30px;
            font-size: 17px;
            font-weight: 700;
            background: var(--blue);
            color: white;
            cursor: pointer;
            margin: 12px 12px 0 0;
            transition: 0.22s ease;
            box-shadow: 0 14px 28px rgba(0,113,227,0.26);
        }

        button:hover { background: #005bb5; transform: translateY(-3px); }

        .outline {
            background: rgba(255,255,255,0.14);
            border: 1px solid rgba(255,255,255,0.22);
            box-shadow: none;
        }

        .workflow {
            display: grid;
            grid-template-columns: repeat(auto-fit, minmax(210px, 1fr));
            gap: 18px;
            margin-top: 34px;
        }

        .workflow-step {
            position: relative;
            padding: 30px;
            border-radius: 28px;
            background: rgba(255,255,255,0.08);
            border: 1px solid rgba(255,255,255,0.13);
            min-height: 190px;
        }

        .number {
            width: 42px;
            height: 42px;
            display: grid;
            place-items: center;
            border-radius: 50%;
            background: var(--blue);
            color: white;
            font-weight: 800;
            margin-bottom: 18px;
        }

        .question {
            margin-top: 26px;
            padding: 26px;
            border-radius: 26px;
            background: rgba(0,113,227,0.10);
            border: 1px solid rgba(0,113,227,0.18);
        }

        footer { padding: 48px 10%; color: #6e6e73; font-weight: 600; }
    </style>
</head>

<body>
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

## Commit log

2026-09-10 PulseCraft PPG 1.0.0 — an open photoplethysmography teaching kit
    Five hands-on PPG projects (activity recognition, caffeine response, relaxation
    biofeedback, a voluntary-apnea SpO2 proxy, and mental-stress detection), each
    following a collect -> analyze/train -> run-live workflow.
    Includes Arduino UNO and Feather ESP32-C6 acquisition firmware, a 3D-printable
    MAX3010x sensor case, Python feature-extraction and machine-learning pipelines,
    a no-hardware signal simulator, full documentation, and an instructor kit
    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
    [max30102_base.stl, max30102_shell.stl]
2026-09-10 Rewrite the docs in plain prose
    Remove the AI-tell punctuation across the README and all docs. No colons before
    lists, no spaced em-dashes, no arrow chains. Reword from 'students / teaching'
    to plain second person. Same information, plainer voice.

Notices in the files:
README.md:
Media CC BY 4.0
